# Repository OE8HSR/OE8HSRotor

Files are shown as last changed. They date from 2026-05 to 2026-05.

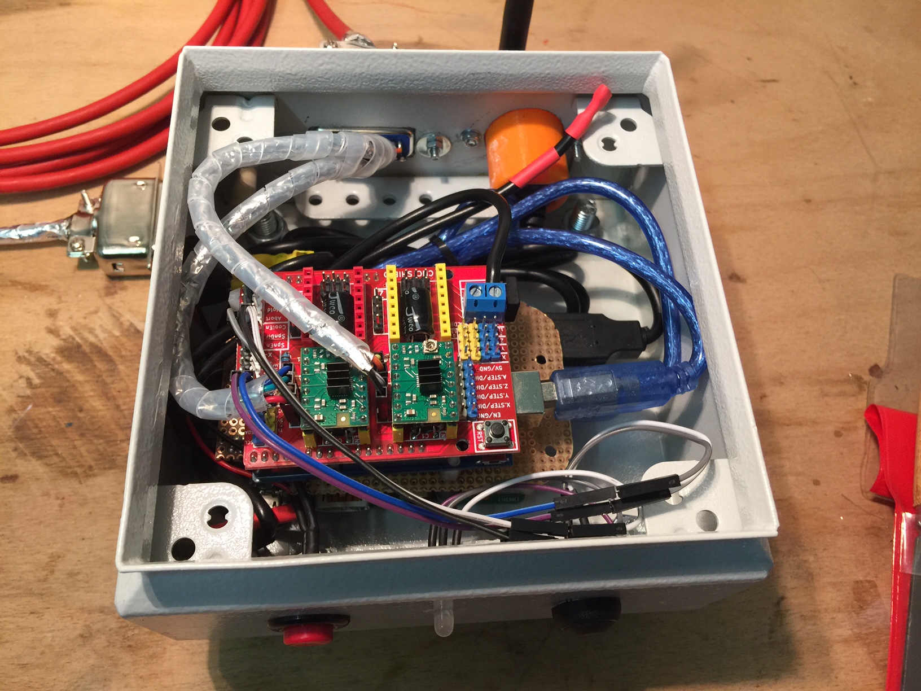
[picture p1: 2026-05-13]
Dokumentation/image2.jpg

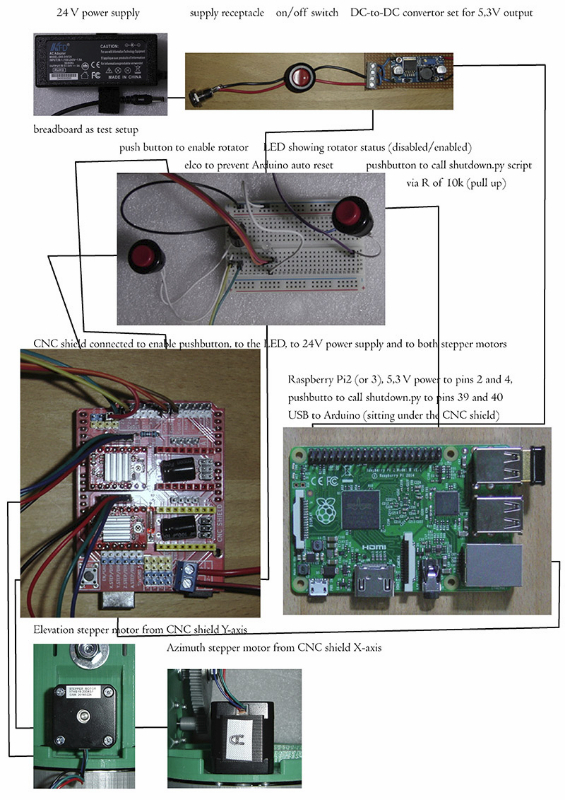
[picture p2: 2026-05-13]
Dokumentation/OE8HSR-Elektronik.jpg

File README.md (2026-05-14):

# OE8HSRotor

Kleiner **Azimut- und Elevations-Antennenrotor**, überwiegend **3D-gedruckt**, mit Schrittmotorantrieb und Arduino-Firmware. Das Projekt entstand **2014** als Eigenbau für den Amateurfunk; Steuerung erfolgt seriell (EasyComm-ähnliches Protokoll). Stand heute gibt es **mechanisch und elektronisch** viele sinnvolle **Weiterentwicklungs- und Vereinfachungsmöglichkeiten** — die vorliegende Doku und Firmware sind bewusst als **historischer Referenzstand** zu verstehen.

**Upstream-Repository:** [OE8HSR/OE8HSRotor auf GitHub](https://github.com/OE8HSR/OE8HSRotor)

---

## Überblick

- **Zwei Achsen:** Azimut (AZ) und Elevation (EL), jeweils mit NEMA-17-Schrittmotor und Getriebeübersetzung (in der Firmware als `RATIOAZ` / `RATIOEL` hinterlegt).
- **Nullstellung (`ZEROSW`):** Das ist **kein automatischer Homing-Endschalter**. Nach dem Einschalten richtest du die **AZ-Achse von Hand nach Norden** aus und stellst **EL waagerecht** ein. Anschließend drückst du den **Zero-Schalter** manuell — dadurch werden die Schrittmotoren **aktiviert** und die aktuelle Lage als **Referenz (0° / 0°)** **festgehalten** (Motoren halten die Position).
- **Serielle Schnittstelle:** 19200 Baud; Befehle für Zielwinkel, Positionsabfrage und Reset (Details in den Kommentaren der `.ino`-Dateien).
- **Firmware-Basis:** inspiriert von früher [SatNogs](https://satnogs.org)-Arduino-Firmware (Hinweis im Quellcode der Originalvariante).

**Sicherheit:** Rotierende Teile und automatische Bewegung können Verletzungen oder Beschädigungen verursachen. Nutzung auf **eigenes Risiko**; Finger und teure Hardware von beweglichen Teilen fernhalten.

### Stand der Elektronik (2014 vs. heute)

Die beschriebene **Elektronik** (Arduino, CNC-Shield, Raspberry Pi als Umgebung usw.) entspricht **nicht mehr** dem heutigen Stand der Technik und hat **deutliches Verbesserungspotenzial**: weniger Bauteile, modernere Treiber, bessere Integration von USB/WLAN und klarere Software-Architektur wären heute deutlich einfacher umzusetzen.

Ein Beispiel für eine **kompaktere Zwei-Achsen-Steuerung** mit integriertem **ESP32** und **TMC2209** ist das Board [**TMC2209 Pen Laser V2**](http://wiki.fluidnc.com/en/hardware/official/TMC2209_Pen_Laser_V2) im FluidNC-Wiki. Mit passender Firmware (z. B. **FluidNC** und einer darauf aufsetzenden Rotor-Logik bzw. Schnittstelle) ließen sich **Elektronikaufwand** und **Bedienung** gegenüber dem 2014er-Aufbau **spürbar vereinfachen** — das ist jedoch **kein Teil dieses Repos**, sondern eine mögliche Richtung für einen Nachfolgebau.

---

## Repository-Inhalt

| Bereich | Beschreibung |
|---|---|
| [**STL/**](STL/) | Druckbare `.STL`-Teile (Getriebe, Gehäuse, Motorhalter, Adapter für verschiedene Antennen). |
| [**Firmware/**](Firmware/) | Arduino-Sketches für die Steuerung (siehe unten). |
| [**Dokumentation/**](Dokumentation/) | Stücklisten, Bauanleitung als PDF, Fotos. |

### Firmware

| Datei | Zweck |
|---|---|
| [`Firmware/OE8HSRotorMK-1.ino`](Firmware/OE8HSRotorMK-1.ino) | **Original-Firmware** (MK-1): serielle Befehle für AZ/EL, kombinierte Positionsabfrage `AZ EL`. Benötigt u. a. die Arduino-Bibliothek **AccelStepper**. |
| [`Firmware/OE8HSRotorMK-1-gpredict-hamlib/OE8HSRotorMK-1-gpredict-hamlib.ino`](Firmware/OE8HSRotorMK-1-gpredict-hamlib/OE8HSRotorMK-1-gpredict-hamlib.ino) | **Variante für gpredict / Hamlib (`rotctld`):** Antworten auf einzelne `AZ`- und `EL`-Positionsabfragen (EasyComm II), Zeilenenden `\r`/`\n`, damit Tracking mit **gpredict** zuverlässiger funktioniert. Im Dateikopf: Beispielaufruf für `rotctld`. |

Abhängigkeiten in den Sketches: `AccelStepper`, `EEPROM` (letzteres wird im aktuellen Stand der MK-1-Dateien eingebunden; bei Bedarf für zukünftige Kalibrierung o. Ä.).

### Dokumentation (Auswahl)

| Datei | Inhalt |
|---|---|
| [`Dokumentation/Partslist_Printed-1.txt`](Dokumentation/Partslist_Printed-1.txt) | Liste der **gedruckten** Teile inkl. optionaler Adapter (z. B. ELK, Arrow). |
| [`Dokumentation/Mechanical_Partslist.txt`](Dokumentation/Mechanical_Partslist.txt) | **Mechanische** Kleinteile (Schrauben, Lager, Gewindestangen, …). |
| [`Dokumentation/Stückliste-EL-1.txt`](Dokumentation/Stückliste-EL-1.txt) | **Elektronik**-Stückliste mit Bezugsquellen (Stand der Datei; Links/Händler nur als historische Referenz). |
| [`Dokumentation/OE8HSRotor01.pdf`](Dokumentation/OE8HSRotor01.pdf) | Dokumentation / Zeichnungen zum Aufbau. |
| [`Dokumentation/Beschreibung-Deutsch.pdf`](Dokumentation/Beschreibung-Deutsch.pdf) | Beschreibung auf Deutsch. |
| Bilder (`image1.jpg`, `image2.jpg`, `OE8HSR-Elektronik.jpg`, …) | Fotos vom Aufbau und der Elektronik. |

### 3D-Druck

Alle Modelle liegen unter [`STL/`](STL/). Die gedruckte Stückliste verweist u. a. auf **80 % Infill** für `16-Stativhalterung` — siehe [`Partslist_Printed-1.txt`](Dokumentation/Partslist_Printed-1.txt).

---

## Kurzstart (Firmware)

1. **Arduino IDE** (oder PlatformIO) mit passendem Board-Paket.
2. Bibliothek **AccelStepper** installieren.
3. Passenden Sketch wählen (Standard **MK-1** oder **gpredict-Hamlib**-Variante).
4. **Pin-Belegung** und **Getriebefaktoren** (`SPR`, `RATIOAZ`, `RATIOEL`) an deine Mechanik anpassen, falls abweichend.
5. Seriell **19200** Baud; für gpredict ggf. `rotctld` wie im Kopf der Hamlib-Variante beschrieben.
6. **Inbetriebnahme:** AZ von Hand nach Norden, EL waagerecht, dann `ZEROSW` drücken (siehe Abschnitt *Überblick*).

---

## Mitwirken

Der Autor schreibt im Quellcode selbstironisch von „Metallworker-Code“ — Verbesserungen und saubere PRs sind willkommen.

---

## Danksagung / Quellen

- Anknüpfung an Ideen aus der frühen **SatNogs**-Firmware (siehe Kommentar in [`OE8HSRotorMK-1.ino`](Firmware/OE8HSRotorMK-1.ino)).

---

*Projekt: **OE8HSRotor** — mostly 3D printed small antenna rotor.*

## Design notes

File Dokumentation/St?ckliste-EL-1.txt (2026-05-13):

OE8HSRotor Electrical Partslist
The Sellers mentiond in this File are the Sellers where i bought my Parts.
I have no connection to this Companies in any Way.
You may find the Parts cheaper somewhere.

Farnell:

7 x DistanceBolt M3x10 						1733428
3 x DistanceBolt M3x15 						2494592
6 x Nut M3 7016943

I would highly suggest to buy more of this Distancebolts and Nuts because they are very handy and you loose them a lot.

Reichelt:

4 x Click on Ferrite Diameter 5mm  			FERRITRING 5,0
3 x Click on Ferrite Diameter 3,5mm  		FERRITRING 3,5
1 x RaspberryPi2B 							RASPBERRY PI 2 B
1 x MicroSdCard 8GB							INTENSO 3413460
1 x Protoboard								H25PR075
1 x PCB Connector Cable						PS 25/2G BR	
2 x Resistor 10KO							METALL 10,0K
1 x ScrewTerminal 4							AKL 055-04
2 x SocketStrip								MPE 094-2-012
2 x Jumper									JUMPER 2,54 SW
1 x Cable									LITZE BL
1 x ButtonSwitch							MS 131 RT
1 x LED Red/Green							LED 5 RG-3
1 x Resistor 120 Ohm						METALL 120
1 x PowerSwitch								DS 059 SW
1 x D2,1mm Connector Female					HEBLM 21
1 x D2,1mm Connector Male					DELOCK 65396
2 x Centronic Connector for Housing			SE 5724F
2 x Centronic Connector for Cable			SE 5724M
1 x Patchcable 5m							PATCH-300 5 GR
1 x USB Extension Cable						AK 669-0,3
1 x Capacitor 10 uF							RAD KXJ 10/400
1 x Wrapping Tube							SPIRAL 20-3

Amazon:
1 x DC/DC Converter http://www.amazon.de/Neuftech-Heruntergehen-Schaltreglermodul-verstellbarer-Abwärtswandler/dp/B00QFDRR9S/ref=sr_1_1?ie=UTF8&qid=1463835386&sr=8-1&keywords=dc+dc+wandler

1 x 40pcs Female/Female Jumper Cable
http://www.amazon.de/Aukru-20cm-female-female-Steckbr%C3%BCcken-Drahtbr%C3%BCcken/dp/B00OL6JZ3C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

1 x Metal Box Rittal KL 1514.510
http://www.amazon.de/Rittal-1514510-Klemmenkasten-KL-1514-510/dp/B0018L5JLK

1 x 10PCS Plugs 10mm
http://www.amazon.de/Stück-Stopfen-Abdeckung-schwarz-Hartplastik/dp/B00OWVRPN8/ref=sr_1_1?ie=UTF8&qid=1463837510&sr=8-1&keywords=stopfen+10mm

1 x Wifi Stick (its the only one that works well with RaspberryPi in my Opinion)
http://www.amazon.de/MP02-USB-Modul-Antenne-Raspberry-Computer/dp/B00KAE1ESI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

AliExpress:

1 x ArduinoClone
http://pt.aliexpress.com/item/Free-shipping-UNO-R3-AVR-MicroController-Board-base-on-DIP-ATmega328-with-USB-Cable-For-Arduino/32240189592.html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,searchweb201602_5_10017_10034_10021_507_10022_10020_10009_10008_10018_10019,searchweb201603_7&btsid=008a2045-263f-4321-83f0-3cb9d97a7e23

1 x CNC Board including Stepper Drivers
http://pt.aliexpress.com/item/Free-Shipping-4-X-A4988-Stepper-Driver-Module-with-Heat-Sink-CNC-Shield-Expansion-Board-for/32464507585.html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,searchweb201602_5_10017_10034_10021_507_10022_10020_10009_10008_10018_10019,searchweb201603_7&btsid=eec38d93-b556-4900-9a4b-cebde8d80362

Printed Parts:
1 x 22_USBBuchse

Mechanical Parts:
4 x Screw M3x15
4 x Spacer M3
4 x Nut M3
1 x Hook for MetalBox

Build Materials:

Shrinking Tubes in different colour and Diameters
Solder 
Siliconcable 2,5mm^2

AluminiumTape
http://www.amazon.de/tesa-Aluminiumband-selbstklebend-50mm-silber/dp/B0049OVT1C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

You may also want to buy:

1 x 24V Power-Supply
http://www.amazon.de/KFD-Universal-Transformator-Bildschirm-Stromkabel/dp/B00ZEDZRGA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

1 x Velcro "Zipties"
http://www.amazon.de/Hama-Klett-Kabelbinder-Schnalle-St%C3%BCck-farbig/dp/B0002W6A46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

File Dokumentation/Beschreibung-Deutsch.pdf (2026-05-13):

## OE8HSRotor

Zu meiner Person:
Mein Name ist Hans Michael Steiner aus Kärnten in Österreich. Seit 3.3.2014 bin Ich im Besitz einer AmateurfunkLizenz mit dem Rufzeichen OE8HSR. Den Vorbereitungskurs für die Amateurfunkprüfung habe Ich in Klagenfurt in der HTL1 Lastenstrasse gemacht der vom ÖVSV angeboten wurde. Beruflich bin Ich Fertigungstechniker im Bereich Land und Forstmaschinen. In meiner Freizeit beschäftige Ich mich mit allerhand Basteleien rund um Elektronik und Amateurfunk.

Wie kam es zu diesem Projekt:
Während meiner Amateurfunkausbildung habe Ich vom Funkbetrieb über Amateurfunksatelliten gehört und fand das das ein sehr spannendes Thema ist. Die Möglichkeit mit anderen Leuten über Satelliten zu kommunizieren die von Funkamateuren gebaut und betrieben werden hat mich derart fasziniert das ich mich mehr mit diesem Thema beschäftigen wollte. Ich habe der ersten Versuche mit LEO Satelliten mit einer kleinen Richtantenne im Garten gemacht, musste jedoch schnell feststellen das es für den Anfänger sehr schnell Unübersichtlich wird.
Die Antenne in einer Hand, das Funkgerät in der anderen, Mit einem Blick auf die Trackingsoftware und mit einem anderen auf dem Kompass.
Ich konnte Zwar einige Satelliten empfangen jedocht war an einen Funkkontakt nicht zu denken.
In diesem Moment war der Entschluss gefasst das es doch eine Möglichkeit geben muss die Antenne von selbst auf den Satelliten zeigen zu lassen. Ich habe lange im Internet nach AntennenRotatoren gesucht, fand jedoch nur einige Selbstbauprojekte und kommerzielle Rotoren die für den Stationären Betrieb gedacht sind und sehr teuer waren. Normalerweise bin ich nicht der Mensch der das Rad neu erfindet aber alles was es zu kaufen gab passte nicht in meine Vorstellung, also musste ich selbst etwas machen.

Meine Vorstellung von MEINEM perfekten Rotor:
Meine Vorstellung von einem perfekten Rotor war anscheinend nicht der Mainstream, deswegen habe ich mir einige Zeit lang Gedanken gemacht wie denn der für mich perfekte Rotor aussehen sollte:
- Der Rotor soll klein, leicht und mobil sein und jederzeit auf einem Stativ aufgestellt werden können
- Die Bedienung soll über ein Smartphone oder Tablet möglich sein.
- Für die Steuerung sollen keine Kabel Notwendig sein.
- Als Stromquelle sollen ganz normale Akkus ausreichen (zwischen 12 und 24V)
- Die Bauteile sollen möglichst 3D gedruckt werden
- Die Bauteile die zugekauft werden müssen sollen möglichst leicht zugänglich sein
- Der Bau des Rotors soll in einem finanziell vertretbaren Rahmen sein.

Mein Plan war das ich einen leichten und portablen AntennenRotor konstruiere den ich dann mit der Hilfe meines 3D Druckers ausdrucke. Mir war wichtig das ich fast alles aus 3D gedruckten Bauteilen mache damit die Materialbeschaffung einfacher wird. Ich wollte auch nicht ein anderes Rohmaterial verwenden das mit Hobbywerkzeugen schwer zu bearbeiten

ist.

Der Prototyp:
Im Frühjahr 2014 habe ich dann begonnen den ersten Prototyp des AntennenRotors zu konstruieren. Damals wusste ich noch nicht auf welche Probleme ich im Verlauf des Projektes stossen werde. Die ersten Bauteile waren auch schnell gedruckt und für gut befunden.

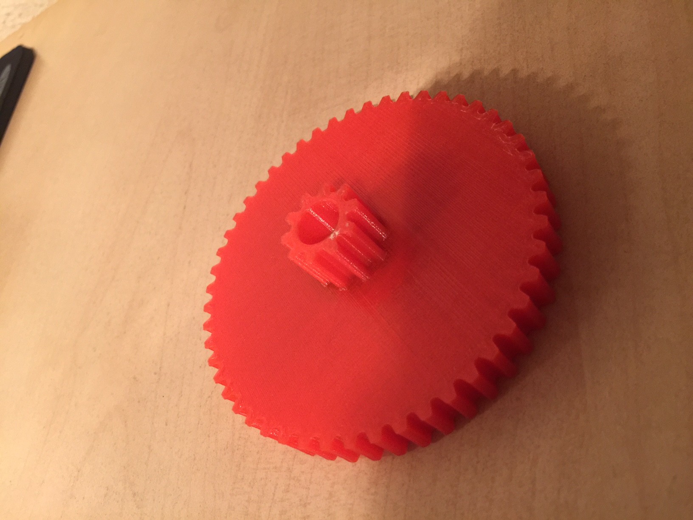
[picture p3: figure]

Durch einem Umzug wurde das Rotorprojekt für einige Zeit auf Eis gelegt und ich konnte erst in den Weihnachtsfeiertagen weiterarbeiten.

Als alles ausgedruckt war mussten die Teile nur noch zusammengebaut werden. Für die Verkabelung waren noch keine Kanäle vorgesehen da es sich ja nur um einen Prototyp gehandelt hat. Nun war es Zeit die Elektronik in angriff zu nehmen. Ich habe auf einer Lochrasterplatine eine kleine Steuerung aufgebaut die im wesentlichen aus einem DC/DC Wandler, einem Arduino Micro und 2 Schrittmotortreibern bestand. Als Steuercomputer verwendete ich einen Raspberry Pi2 mit Wifi anbindung.

Die ersten Tests waren vielversprechend.

Der Rotor sah zu diesem Zeitpunkt noch sehr wüst aus, funktionierte aber technisch einwandfrei.
Ich bemkerte jedoch schnell das die Steuerelektronik Störsignale in die Antenne abstrahlt. Eine Lösung musste her...

Die Version 1.0:
Durch die Tests mit dem Prototyp habe Ich einige Verbesserungsmöglichkeiten bemerkt. Es hatte keinen Sinn den bestehenden Prototyp umzubauen da fast alle Teile verbesserungswürdig waren. Also beschloss ich im Sommer 2015 eine neue Version des Rotors zu konstruieren.
Die Verbesserungen waren:
- Veränderung der Drehlagerung zum den Rotor zu Stabilisieren.
- Verbesserung der Demontage
- Bessere verlegemöglichkeit der Kabel
- zusätzliche Halterung für Antennen an den Seiten
- Durchgangsbohrungen für Antennenkabel
- Halterungen für Akkus

Wie immer hat das Projekt während der Weihnachtsfeiertage einen Schub gemacht.

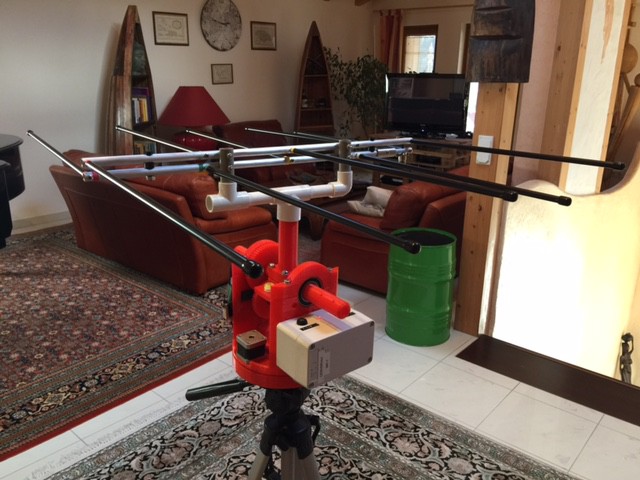
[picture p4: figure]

Die Steuerbox:
Die Steuerung des Rotors hat mich wahrscheinlich am meisten an den Rand der Verzweiflung gebracht. Wie oben schon beschrieben hatte ich Probleme mit Störsignalen die in die Antenne abgestrahlt sind. Das Hauptproblem war das die Steuerelektronik sehr nahe an der Antenne und direkt am Rotor montiert war.

Als Lösung dieses Problems habe ich eine Box aus Stahl gekauft und die Elektronik in diese eingebaut. Als Verbindungskabel Zwischen Rotor und Steuerbox verwende ich ein geschirmtes Kabel mit Centronic Steckern.

Durch dieses Vorgehen haben sich die Störsignale fast vollständig reduziert.

Technische Beschreibung:
Die Steuerelektronik des Rotors läuftso:
Der Raspberry Pi Computer verbindet sich über einem Wifi USB Stick mit einem Netzwerk welches man zuvor eingestellt hat (entweder zu einem im Haus oder einem Mobilen Hotspot. Man könnte auch den Raspberry Pi als Hotspot selbst configurieren).
Der Raspberry sendet über eine Serielle Schnittstelle die Aktuellen Rotor Daten (Azimuth und Elevation) an den Arduino. Der Arduino empfängt die Daten und steuert die Schrittmotoren am Rotor.

Auf dem Pi ist ein VNC Server und die Gpredict Tracking Software installiert.
Nun kann man sich mit einem jeden VNC Client auf dem AntennenRotor verbinden und damit den Rotor Steuern.

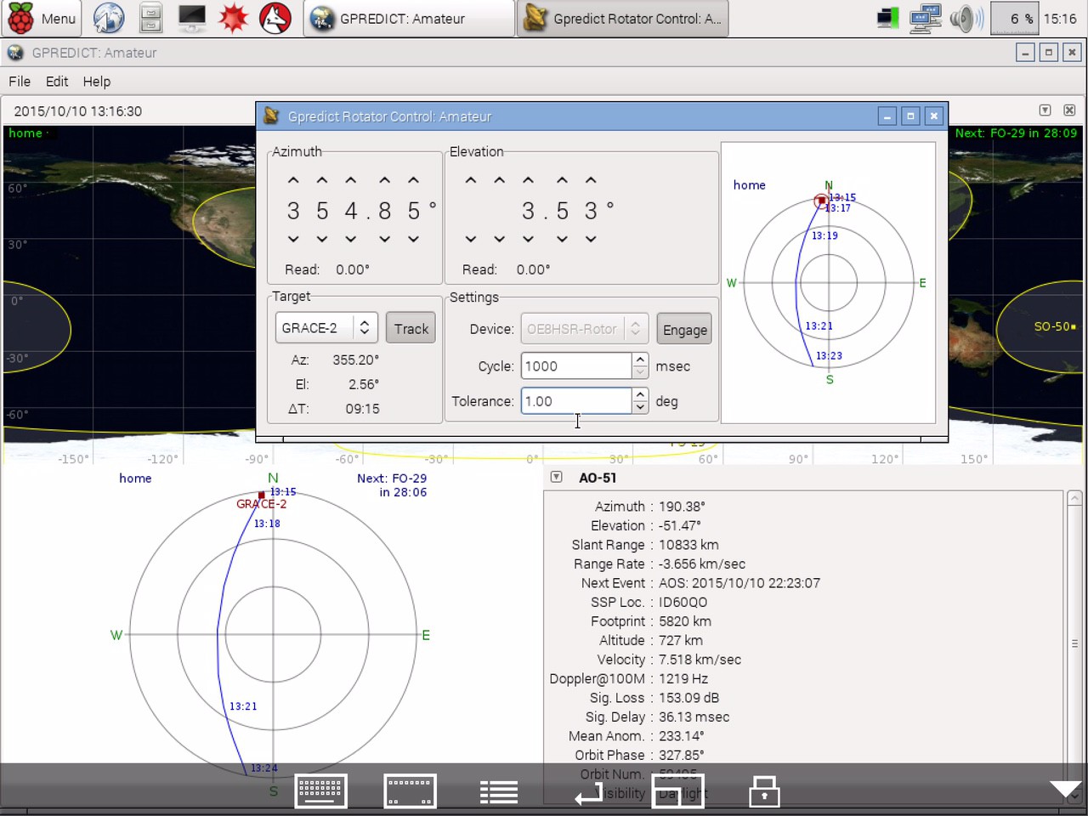
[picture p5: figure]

Die Mechanik:
Ich persönlich bin ein Freund von Projekten die möglichst wenig zukaufteile benötigen. Bei manchen Projekten ist es so das die Beschaffung der Bauteile den meisten Zeitaufwand erfordert. Man muss die benötigten Teile bei verschiedenen Händlern kaufen. Das Ist Zeit intensiv und kostet viel Geld und Nerven.
Bei der Konstruktion habe ich besonderes Augenemerkt darauf gelegt soviel wie möglich selbst zu drucken so das man nur mehr einige Kugellager und Schrauben zukaufen muss.

Der Azimuth Schrittmotor Erzeugt die Drehbewegung des Schrittmotors.Dort ist eine Zahnradübersetzung von 1:10 verbaut. Das bedeutet das sich der Motor 10 mal drehen muss damit sich der Rotor einmal dreht. Durch diese Übersezung Läuft der Rotor ruhig und hat viel Drehmoment.

Die Elevation Stufe besteht aus 2 Übersetzungen. Dort ist eine größere Getriebeübersetzung damit mehr Drehmoment erzeugt wird. Falls man mal die Antenne nicht 100% ausbalanciert bekommt sollte das auch kein Problem sein.

Für die Lagerung der verschiedenen Komponenten habe ich mich für StandardKugellager entschieden damit alles sauber läuft.

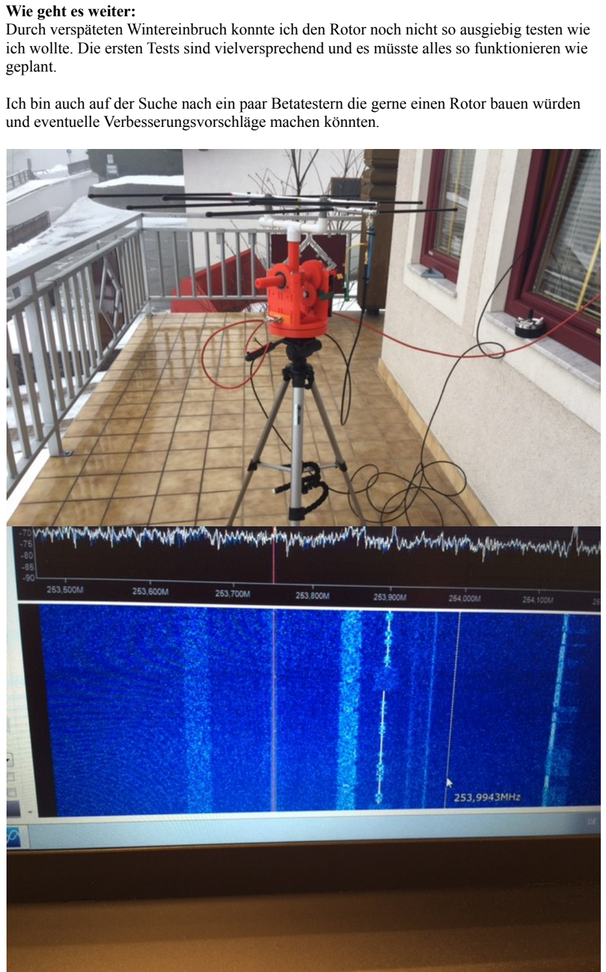
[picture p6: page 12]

Wie geht es weiter:
Durch verspäteten Wintereinbruch konnte ich den Rotor noch nicht so ausgiebig testen wie ich wollte. Die ersten Tests sind vielversprechend und es müsste alles so funktionieren wie geplant.

Ich bin auch auf der Suche nach ein paar Betatestern die gerne einen Rotor bauen würden und eventuelle Verbesserungsvorschläge machen könnten.

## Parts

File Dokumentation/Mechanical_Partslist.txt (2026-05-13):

Mechanical PartsList:

4 x FastbuildScrew M6x60
4 x Spacer M6
1 x Nut ExtraLong M10
2 x Nut ExtraLong M8
1 x ThreadedRod M8x210
1 x Ball Bearing 6000
3 x Ball Bearing 6006
1 x Ball Bearing 51114
1 x Screw M10x50
1 x Nut M10
2 x Spacer M10
1 x Capping Nut M10
2 x StepperMotors Nema17
4 x Screw M3x20
4 x Screw M3x10
8 x Spacer M3
4 x Screw M6x50
8 x Spacer M6
4 x Nut M6
1 x Screw M10x30
2 x Spacer M10 (bigger outer Diameter)
2 x Screw M2.5x10
2 x Spacer M2.5
2 x Nut M2.5

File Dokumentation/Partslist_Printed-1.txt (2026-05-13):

Parts to be Printed

1 x 1-AbtriebWelleKurz
1 x 2-AbtriebsWelleLang
2 x 3-Seitenverlängerung
1 x 4-AbtriebsradZ60
1 x 5-Drehteil
1 x 6-UmlenkradZ10Z50
1 x 7-Verbindungsbolzen
1 x 8-MotorElz10
1 x 9-AbtriebswelleDistanz
1 x 13-Innenverzahnung
2 x 14-LagerhalterungOben
1 x 15-MotorAzZ10
1 x 16-Stativhalerung (USE INFILL 80% ON THAT PART!!)
1 x 17-DrehteilAbdeckKappe
1 x 21-SteckerHalterung
1 x 22-USBBuchse

For ElkAntenna on Top of the Rotor print aditionally:
11-ELKMountObenLang
12-ELKMountUnten

For ElkAntenna on Side of the Rotor print aditionally:
18-Seitenadapter

For ArrowAntenna on Side of the Rotor print aditionally:
19-ArrowSeitenAdapter

For ArrowAntenna on Side of the Rotor on a Tube print aditionally:
20-ArrowBoomAdapter

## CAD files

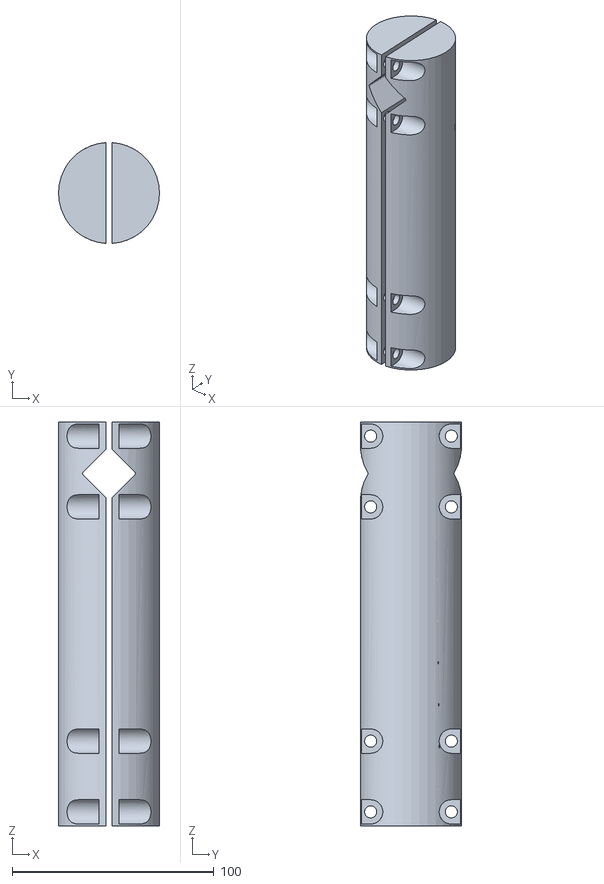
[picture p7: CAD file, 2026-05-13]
STL/19-ArrowSeitenAdapter.STL
50.0 x 49.9 x 200.0

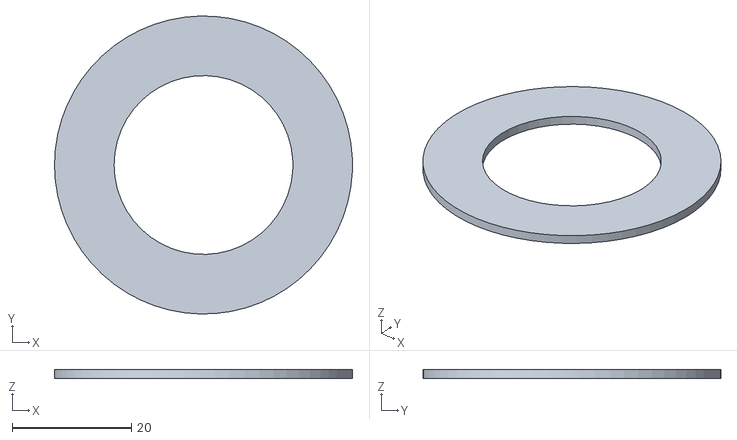
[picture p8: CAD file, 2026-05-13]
STL/10-DistanzUnten.STL
50.0 x 50.0 x 1.50

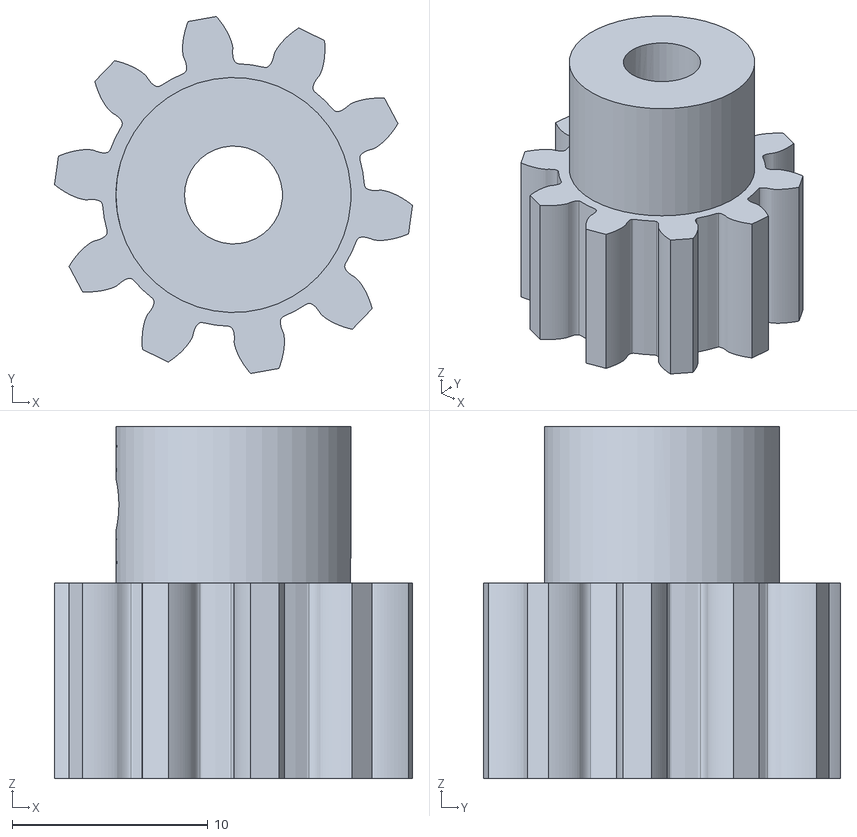
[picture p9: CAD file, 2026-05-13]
STL/15-MotorAzZ10.STL
18.3 x 18.2 x 18.0

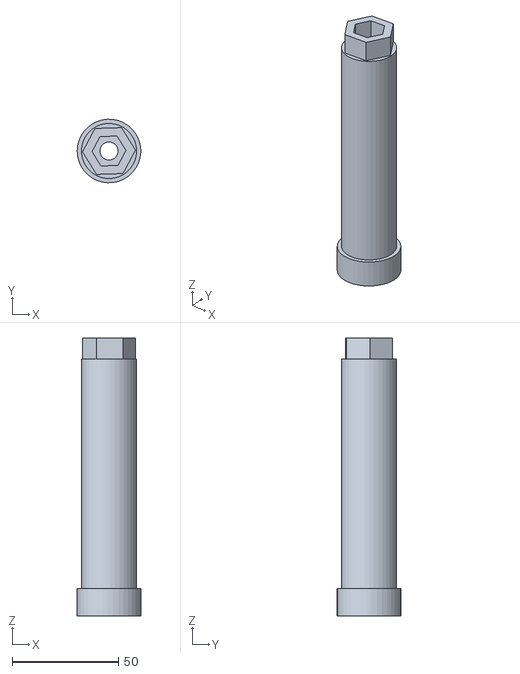
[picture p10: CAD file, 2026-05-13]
STL/2-AbtriebsWelleLang.STL
30.0 x 30.0 x 131.0

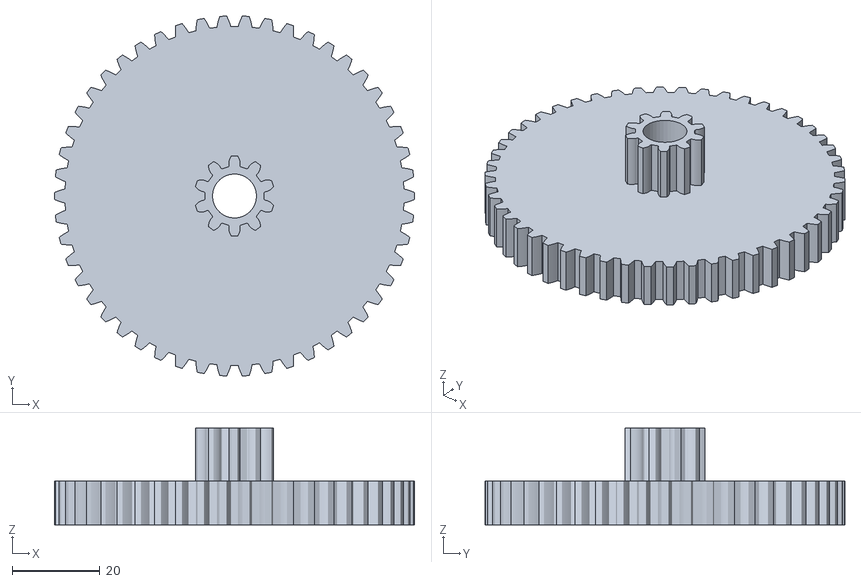
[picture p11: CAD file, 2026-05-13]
STL/6-UmlenkradZ10Z50.STL
82.0 x 81.9 x 22.0

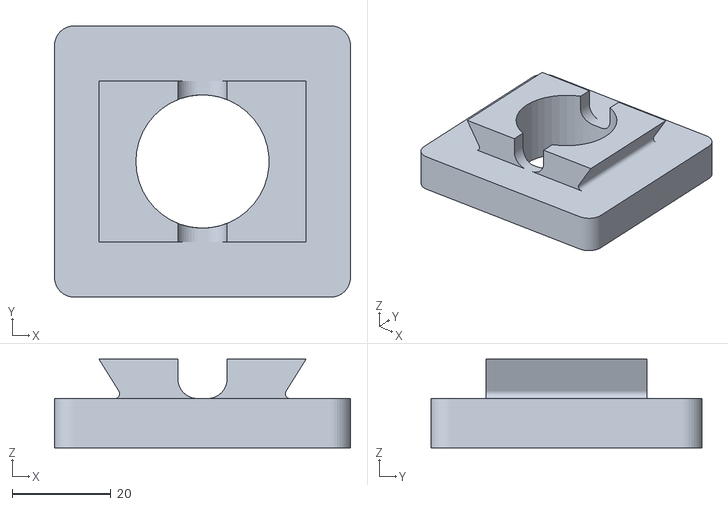
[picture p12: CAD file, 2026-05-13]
STL/16-Stativhalterung.STL
60.0 x 55.0 x 18.0

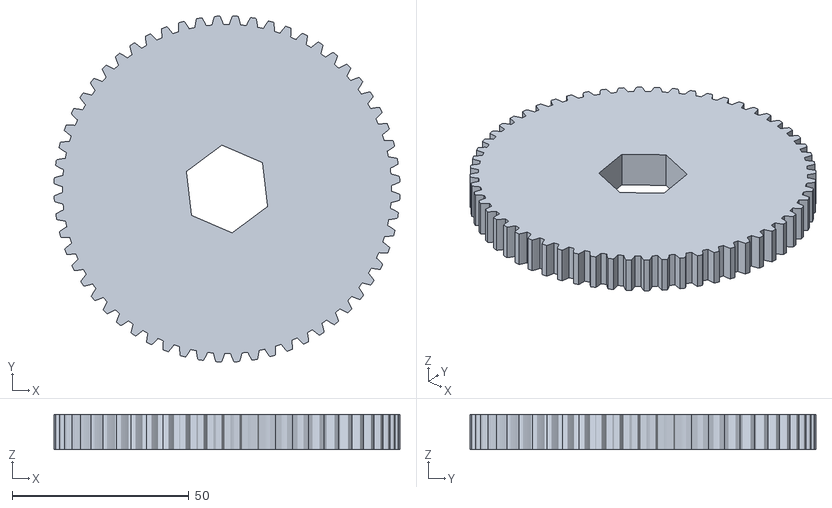
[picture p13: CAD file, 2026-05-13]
STL/4-AbtriebsradZ60.STL
97.8 x 97.8 x 10.0

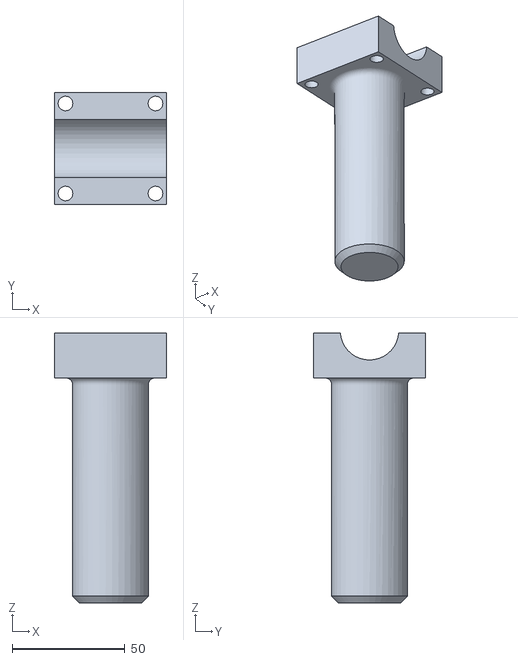
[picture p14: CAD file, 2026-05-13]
STL/11-ELKMountObenLang.STL
50.0 x 50.0 x 120.0

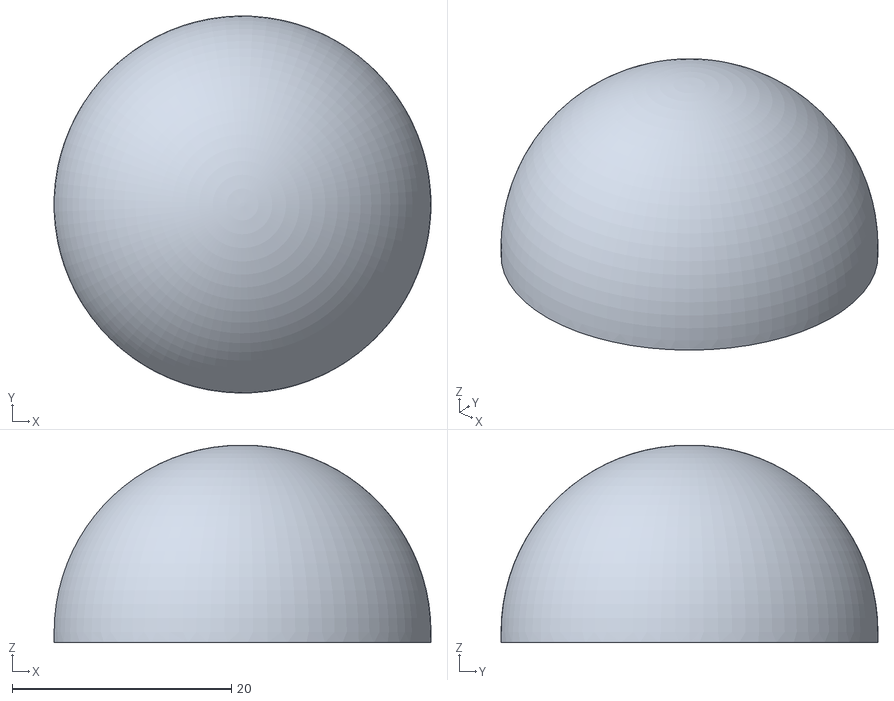
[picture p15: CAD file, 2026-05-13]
STL/17-DrehteilAbdeckKappe.STL
34.4 x 34.4 x 18.0

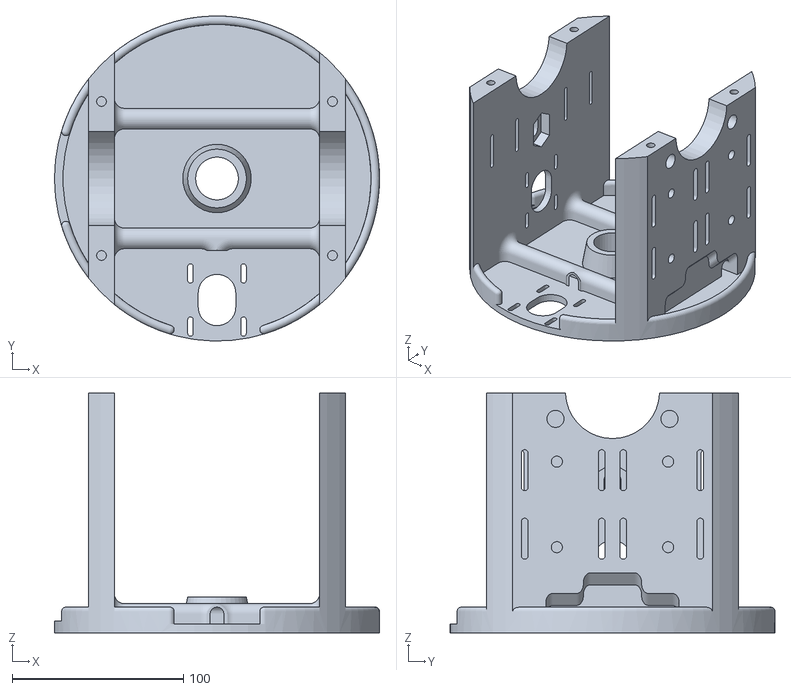
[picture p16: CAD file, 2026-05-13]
STL/5-Drehteil.STL
190.0 x 189.9 x 140.0

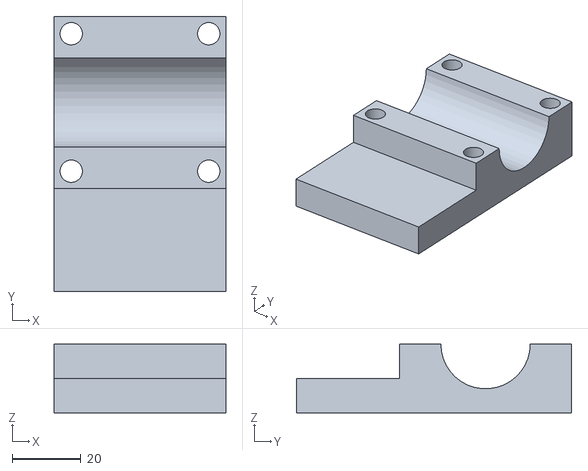
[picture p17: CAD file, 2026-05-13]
STL/12-ELKMountUnten.STL
50.0 x 80.0 x 20.0

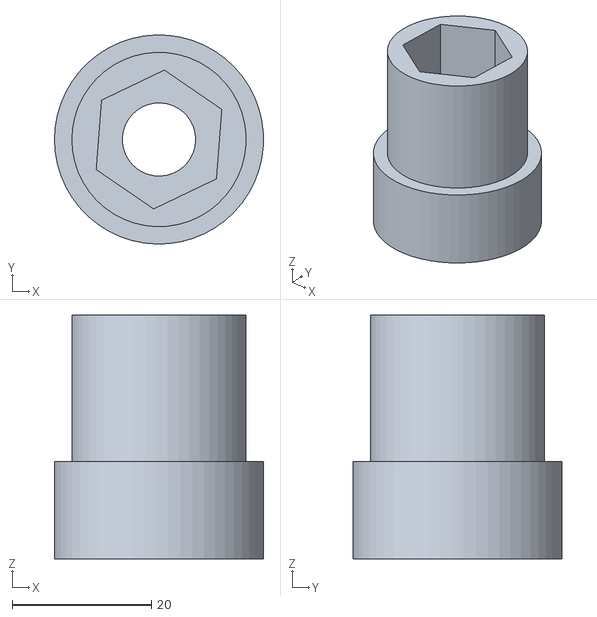
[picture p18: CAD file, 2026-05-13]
STL/7-Verbinungsbolzen.STL
30.0 x 30.0 x 35.0

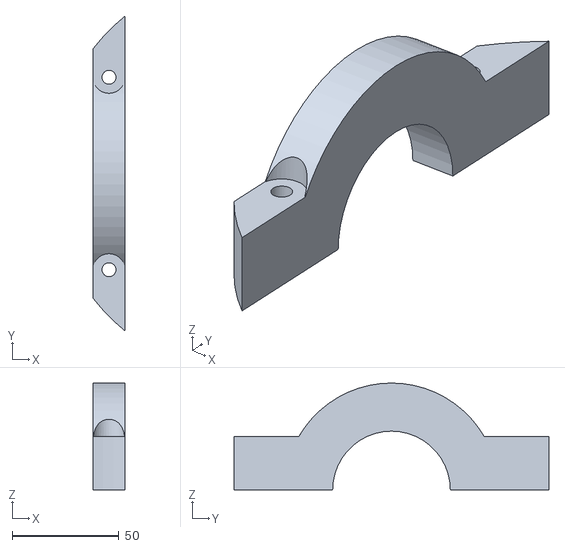
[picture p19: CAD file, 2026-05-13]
STL/14-LagerhalterungOben.STL
15.0 x 147.3 x 50.0

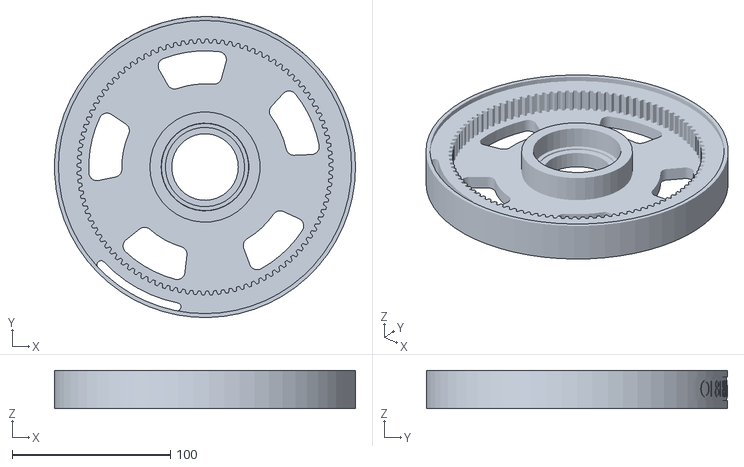
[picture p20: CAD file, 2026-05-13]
STL/13-Innenverzahnung100.STL
190.0 x 190.0 x 24.0

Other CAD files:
STL/21-SteckerHalterung.STL
STL/3-Seitenverlängerung.STL
STL/13-Innenverzahnung100-(OHNE OE8HSRotor Schriftzug).STL
STL/18-SeitenAdapter.STL
STL/1-AbtriebWelleKurz.STL
STL/20-ArrowBoomAdapter.STL
STL/22-USBBuchseSLDPRT.STL
STL/8-MotorELz10.STL
STL/9-AbriebsWelleDistanz.STL

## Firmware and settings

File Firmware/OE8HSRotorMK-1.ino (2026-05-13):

/*
 * Firmware for OE8HSRotor Antenna Rotor Version 0.1
 * This Software uses Parts from the early SatNogs Arduino firmware. Check out their cool Project at www.satnogs.org
 * 
 * Use this Software and the OE8HSRotor Hardware at your own Risk.
 * Always keep in mind that Computer controlled Machines can be dangerous. 
 * Keep your fingers away from rotating parts even if they are small and made out of plastic.
 * 
 * Damages on:
 * Expensive Radio Hardware
 * Expensive Antenna Hardware
 * Expensive Rotor Hardware
 * Human Bodyparts
 * are not the Authors Fault.
 * 
 * Please keep in Mind that this code has been written by a Metallworker. If you think you can make it better and contribute please do so. =)
 */
 
 
#include <math.h>
#include <stdlib.h>
#include <string.h>
#include <AccelStepper.h>
#include <EEPROM.h>

/* Defining Output and Input Pins */
#define DIR_AZ 5 //PIN for Azimuth Direction X
#define STEP_AZ 2 //PIN for Azimuth Steps X
#define DIR_EL 6 //PIN for Elevation Direction Y
#define STEP_EL 3 //PIN for Elevation Steps Y
#define EN 8 //PIN for Enable or Disable Stepper Motors

#define LEDR 13 //PIN for the Red LED
#define LEDG 12 //PIN for the Green LED
#define ZEROSW 11 //PIN for the "Rotor Zeroing Switch"



#define SPR 200 //StepperMotor Stepps/Rev
#define RATIOEL 120 //Gear ratio Elevation: Stage1: 10->50 = 1:5 Stage2: 10->60 = 1:6 Total: 5 x 6 = 30 Elevation runs on quarter stepps so 30 x 4 = 120
#define RATIOAZ 40 //Gear ratio Azimuth: Stage1: 10->100 = 1:10 Azimuth runs on quarter stepps so 10 x 4 = 40


/*Defining Stepper Objects*/
AccelStepper AZstepper(1, STEP_AZ, DIR_AZ);
AccelStepper ELstepper(1, STEP_EL, DIR_EL);

int counter;
bool done;

void setup()
{  
  /*Change values that work for your*/
  AZstepper.setMaxSpeed(1000);
  AZstepper.setAcceleration(500);
  
  /*Change values that work for your*/
  ELstepper.setMaxSpeed(2000);
  ELstepper.setAcceleration(1000);
  
  /*Disable Steppers for zeroing by hand*/
  pinMode(EN, OUTPUT);
  digitalWrite(EN, LOW);
  
  /*Defining LED Outputs*/
  pinMode(LEDG, OUTPUT);
  digitalWrite(LEDG, LOW);
  pinMode(LEDR, OUTPUT);
  digitalWrite(LEDR, LOW);
  
  pinMode(ZEROSW, INPUT);
  digitalWrite(ZEROSW, HIGH);

  Serial.begin(19200);

  counter = 0;
  done = 0;
  

  /*Set Rotor Zero*/
  setZero();
}

void loop()
{ 
  static int AZstep = 0;
  static int ELstep = 0;
  

  cmd_proc(AZstep, ELstep);
  stepper_move(AZstep, ELstep);
  
}
  



/*SetZero*/
void setZero(void)
{
  
  
  while(digitalRead(ZEROSW) != LOW) 
  {
    digitalWrite(LEDR, HIGH);
    digitalWrite(EN, HIGH);
  }
  
  digitalWrite(LEDR, LOW);
  digitalWrite(LEDG, HIGH);
  digitalWrite(EN, LOW);
  
  
  ELstepper.setCurrentPosition(0); 
  AZstepper.setCurrentPosition(0); 
  
}
 
 

void cmd_proc(int &stepAz, int &stepEl)
{
  //Serial
  char buffer[256];
  char incomingByte;
  char data[256];
  
    
    

        if(Serial.available() > 0)
        {
          incomingByte = Serial.read(); // Read a character
          switch (incomingByte) 
          {
             case '\n':
             done = 1;

             break;
             
             case 'U':
             done = 1;

             break;
             
             default: 
             buffer[counter] = incomingByte; // Store it
             counter++; // Increment where to write next
             buffer[counter] = '\0'; // Null terminate the string
             break;
          }
         }


      
if(done)
{
  
         for(int i = 0; i < strlen(buffer); i++)
         {
           if (buffer[i] == 'A' && buffer[i + 1] == 'Z'  && buffer[i + 2] == ' ' && buffer[i + 3] == 'E' && buffer[i + 4] == 'L')
           {
             Serial.print("AZ");
             Serial.print(getAzAngle());
             Serial.print(" ");
             Serial.print("EL");
             Serial.println(getElAngle());

           }
           else if(buffer[i] == 'A' && buffer[i + 1] == 'Z' && isdigit(buffer[i + 2]))
           {
             strncpy(data, buffer+(i+2), 100);
             

             double angleAz = atof(data);

             data[0] = '\0';
 
             stepAz = deg2stepAZ(angleAz);   

             Serial.println("AZ");

           }
           else if(buffer[i] == 'E' && buffer[i + 1] == 'L' && isdigit(buffer[i + 2]))
           {
             strncpy(data, buffer+(i+2), 100);
             

             double angleEl = atof(data);
 
             data[0] = '\0';
 
              stepEl = (deg2stepEL(angleEl)) * -1;  
              Serial.println("EL"); 

           }
           else if (buffer[i] == 'S' && buffer[i + 1] == 'A' && buffer[i + 2] == ' ' && buffer[i + 3] == 'S' && buffer[i + 4] == 'E')
           {
             stepAz = AZstepper.currentPosition();
             stepEl = ELstepper.currentPosition();

           }
           else if (buffer[i] == 'R' && buffer[i + 1] == 'E' && buffer[i + 2] == 'S' && buffer[i + 3] == 'E' && buffer[i + 4] == 'T')
           {
             setZero();

             stepAz = 0;
             stepEl = 0;

           }      

  }
done = 0;
counter = 0;
buffer[0] = '\0';

}
}





/*Send pulses to stepper motor drivers*/
void stepper_move(int stepAz, int stepEl)
{
  AZstepper.moveTo(stepAz);
  ELstepper.moveTo(stepEl);
    
  AZstepper.run();
  ELstepper.run();
}

/*Convert degrees to steps*/
int deg2stepAZ(double deg)
{
  return(RATIOAZ*SPR*deg/360);
}

/*Convert steps to degrees*/
double step2degAZ(int Step)
{
  return(360*Step/(SPR*RATIOAZ));
}

int deg2stepEL(double deg)
{
  return(RATIOEL*SPR*deg/360);
}

/*Convert steps to degrees*/
double step2degEL(int Step)
{
  return(360*Step/(SPR*RATIOEL));
}

float getElAngle(void)
{
  return(step2degEL(ELstepper.currentPosition()));
}

float getAzAngle(void)
{
  return(step2degAZ(AZstepper.currentPosition()));
}

boolean isNumber(char *input)
{
  for (int i = 0; input[i] != '\0'; i++)
  {
    if (isalpha(input[i]))
      return false;
  }
   return true;
}

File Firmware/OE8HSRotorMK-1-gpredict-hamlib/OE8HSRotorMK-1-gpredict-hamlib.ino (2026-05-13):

/*
 * OE8HSRotorMK-1 — Test-Firmware für gpredict / rotctld (Hamlib EasyComm II)
 *
 * rotctld (Seriell → TCP für gpredict) — Baudrate wie Serial.begin() unten (19200):
 *
 *   rotctld -m 202 -s 19200 -r /dev/ttyUSB0 -t 2000 -T 127.0.0.1
 *
 *   -m 202      EasyComm II
 *   -s 19200    wie Serial.begin(19200) in dieser Firmware
 *   -r …       serielles Gerät ggf. anpassen (ttyUSB0, ttyACM0, …)
 *   -t 2000    TCP-Port für gpredict
 *   -T 127.0.0.1  nur localhost
 *
 * Ausgangsbasis: OE8HSRotorMK-1.ino (unverändert im Repo belassen).
 *
 * Hintergrund:
 * Hamlib easycomm_rot_get_position() sendet nacheinander "AZ\n" und "EL\n"
 * und erwartet je eine Zeile "AZ<winkel>" bzw. "EL<winkel>" (sscanf "AZ%f" / "EL%f").
 * Die Original-Firmware antwortet nur auf die zusammengefasste Abfrage "AZ EL",
 * daher schlagen Positionsabfragen fehl — gpredict kann beim Tracking u. a. nicht
 * zuverlässig nachführen.
 *
 * Änderungen in dieser Datei:
 * - Antwort auf Positionsabfrage "AZ" bzw. "EL" (optional mit \r, allein oder mit Leerzeichen)
 * - Zeilenende \r und \n als Befehlsende akzeptiert
 * - Reihenfolge der Parser-Zweige: spezielle / längere Muster vor kürzeren "AZ…"-Zweigen
 */

#include <math.h>
#include <stdlib.h>
#include <string.h>
#include <ctype.h>
#include <AccelStepper.h>
#include <EEPROM.h>

#define DIR_AZ 5
#define STEP_AZ 2
#define DIR_EL 6
#define STEP_EL 3
#define EN 8

#define LEDR 13
#define LEDG 12
#define ZEROSW 11

#define SPR 200
#define RATIOEL 120
#define RATIOAZ 40

AccelStepper AZstepper(1, STEP_AZ, DIR_AZ);
AccelStepper ELstepper(1, STEP_EL, DIR_EL);

int counter;
bool done;

static void strip_cr(char *s)
{
  size_t len = strlen(s);
  while (len > 0 && (s[len - 1] == '\r' || s[len - 1] == '\n'))
  {
    s[len - 1] = '\0';
    len--;
  }
}

static bool az_el_combined_query(const char *buf)
{
  return strstr(buf, "AZ EL") != NULL || strstr(buf, "AZ  EL") != NULL;
}

static void reply_az(void)
{
  Serial.print("AZ");
  Serial.println(getAzAngle(), 1);
}

static void reply_el(void)
{
  Serial.print("EL");
  Serial.println(getElAngle(), 1);
}

void setup()
{
  AZstepper.setMaxSpeed(1000);
  AZstepper.setAcceleration(500);

  ELstepper.setMaxSpeed(2000);
  ELstepper.setAcceleration(1000);

  pinMode(EN, OUTPUT);
  digitalWrite(EN, LOW);

  pinMode(LEDG, OUTPUT);
  digitalWrite(LEDG, LOW);
  pinMode(LEDR, OUTPUT);
  digitalWrite(LEDR, LOW);

  pinMode(ZEROSW, INPUT);
  digitalWrite(ZEROSW, HIGH);

  Serial.begin(19200);

  counter = 0;
  done = 0;

  setZero();
}

void loop()
{
  static int AZstep = 0;
  static int ELstep = 0;

  cmd_proc(AZstep, ELstep);
  stepper_move(AZstep, ELstep);
}

void setZero(void)
{
  while (digitalRead(ZEROSW) != LOW)
  {
    digitalWrite(LEDR, HIGH);
    digitalWrite(EN, HIGH);
  }

  digitalWrite(LEDR, LOW);
  digitalWrite(LEDG, HIGH);
  digitalWrite(EN, LOW);

  ELstepper.setCurrentPosition(0);
  AZstepper.setCurrentPosition(0);
}

void cmd_proc(int &stepAz, int &stepEl)
{
  static char buffer[256];
  char incomingByte;
  char data[256];

  if (Serial.available() > 0)
  {
    incomingByte = Serial.read();
    switch (incomingByte)
    {
    case '\n':
    case '\r':
      done = 1;
      break;

    case 'U':
      done = 1;
      break;

    default:
      if (counter < (int)sizeof(buffer) - 1)
      {
        buffer[counter++] = incomingByte;
        buffer[counter] = '\0';
      }
      else
      {
        counter = 0;
        buffer[0] = '\0';
      }
      break;
    }
  }

  if (done)
  {
    strip_cr(buffer);

    if (az_el_combined_query(buffer))
    {
      Serial.print("AZ");
      Serial.print(getAzAngle(), 1);
      Serial.print(" ");
      Serial.print("EL");
      Serial.println(getElAngle(), 1);
    }
    else
    {
      for (int i = 0; i < (int)strlen(buffer); i++)
      {
        if (buffer[i] == 'R' && buffer[i + 1] == 'E' && buffer[i + 2] == 'S' &&
            buffer[i + 3] == 'E' && buffer[i + 4] == 'T')
        {
          setZero();
          stepAz = 0;
          stepEl = 0;
        }
        else if (buffer[i] == 'S' && buffer[i + 1] == 'A' && buffer[i + 2] == ' ' &&
                 buffer[i + 3] == 'S' && buffer[i + 4] == 'E')
        {
          stepAz = AZstepper.currentPosition();
          stepEl = ELstepper.currentPosition();
        }
        else if (buffer[i] == 'E' && buffer[i + 1] == 'L' &&
                 (isdigit((unsigned char)buffer[i + 2]) || buffer[i + 2] == '.' ||
                  buffer[i + 2] == '-' || buffer[i + 2] == '+'))
        {
          strncpy(data, buffer + (i + 2), sizeof(data) - 1);
          data[sizeof(data) - 1] = '\0';
          double angleEl = atof(data);
          stepEl = (deg2stepEL(angleEl)) * -1;
          Serial.println("EL");
        }
        else if (buffer[i] == 'A' && buffer[i + 1] == 'Z' &&
                 (isdigit((unsigned char)buffer[i + 2]) || buffer[i + 2] == '.' ||
                  buffer[i + 2] == '-' || buffer[i + 2] == '+'))
        {
          strncpy(data, buffer + (i + 2), sizeof(data) - 1);
          data[sizeof(data) - 1] = '\0';
          double angleAz = atof(data);
          stepAz = deg2stepAZ(angleAz);
          Serial.println("AZ");
        }
        else if (buffer[i] == 'A' && buffer[i + 1] == 'Z')
        {
          char c = buffer[i + 2];
          if (c == '\0' || c == ' ' || c == '\t')
            reply_az();
        }
        else if (buffer[i] == 'E' && buffer[i + 1] == 'L')
        {
          char c = buffer[i + 2];
          if (c == '\0' || c == ' ' || c == '\t')
            reply_el();
        }
      }
    }

    done = 0;
    counter = 0;
    buffer[0] = '\0';
  }
}

void stepper_move(int stepAz, int stepEl)
{
  AZstepper.moveTo(stepAz);
  ELstepper.moveTo(stepEl);

  AZstepper.run();
  ELstepper.run();
}

int deg2stepAZ(double deg)
{
  return (RATIOAZ * SPR * deg / 360);
}

double step2degAZ(int Step)
{
  return (360 * Step / (SPR * RATIOAZ));
}

int deg2stepEL(double deg)
{
  return (RATIOEL * SPR * deg / 360);
}

double step2degEL(int Step)
{
  return (360 * Step / (SPR * RATIOEL));
}

float getElAngle(void)
{
  return (float)step2degEL(ELstepper.currentPosition());
}

float getAzAngle(void)
{
  return (float)step2degAZ(AZstepper.currentPosition());
}

boolean isNumber(char *input)
{
  for (int i = 0; input[i] != '\0'; i++)
  {
    if (isalpha(input[i]))
      return false;
  }
  return true;
}

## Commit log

2026-05-13 file upload
    [1-AbtriebWelleKurz.STL, 10-DistanzUnten.STL, 11-ELKMountObenLang.STL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]
2026-05-13 Revise README with project details in German
    Updated the README to provide detailed project information in German, including features, system architecture, and software flow.
